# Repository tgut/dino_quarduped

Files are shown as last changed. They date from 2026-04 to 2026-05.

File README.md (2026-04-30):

# Dino Quadruped — 四足机器恐龙

基于 SpotMicro 硬件平台 + CHAMP 软件框架的四足机器恐龙项目，使用强化学习 (PPO) 训练行走策略。

## 项目结构

```
dino_quadruped/
├── urdf/                    # 机器人 URDF 模型
│   └── dino_quadruped.urdf  # 12-DOF SpotMicro 模型
├── rl/                      # 强化学习核心代码
│   ├── dino_env.py          # Gymnasium + PyBullet 仿真环境
│   ├── train_ppo.py         # PPO 训练脚本 (Stable-Baselines3)
│   └── record_eval_video.py # 评估视频录制
├── scripts/                 # 工具脚本
│   ├── benchmark.py         # 性能基准测试
│   ├── sim_standalone.py    # 独立仿真测试
│   └── ...                  # 诊断、可视化等脚本
├── docs/                    # 项目文档
│   ├── rl_v6_training_summary.md  # v6 训练总结报告
│   ├── hardware_architecture.md   # 硬件架构
│   ├── mechanical_design.md       # 机械结构设计
│   └── wiring_diagram.md         # 接线图
├── eval_output/             # 评估产出
│   ├── rl_v6_policy.mp4    # v6 策略行走视频
│   ├── baseline_v6.mp4     # baseline 对比视频
│   ├── training_curves_v6.png # 训练曲线
│   └── eval_v6_summary.json   # 评估指标
├── rl_logs/                 # 训练日志
│   ├── models/              # 模型 checkpoints
│   ├── tensorboard/         # TensorBoard 日志
│   └── training_log.json    # 训练过程记录
├── eval_v6.py               # v6 完整评估流水线
└── README.md
```

## 机器人参数

| 参数 | 值 |
|---|-----|
| 自由度 | 12 DOF (4腿 × 3关节) |
| 体重 | 1.5 kg |
| 体尺寸 | 200×110×60 mm |
| 腿长 | 上腿 100mm + 下腿 100mm |
| 仿真引擎 | PyBullet |

## 快速开始

### 环境安装

```bash
pip install stable-baselines3 gymnasium pybullet numpy
```

### 训练

```bash
# 默认 5M 步，8 并行环境
python rl/train_ppo.py

# 自定义参数
python rl/train_ppo.py --timesteps 2000000 --num-envs 4

# 从 checkpoint 恢复训练
python rl/train_ppo.py --resume
```

### 评估

```bash
# 运行评估 (10 episodes)
python rl/train_ppo.py --eval

# 录制评估视频
python rl/record_eval_video.py

# 完整 v6 评估流水线
python eval_v6.py
```

### TensorBoard 监控

```bash
tensorboard --logdir rl_logs/tensorboard
```

## RL 训练版本演进

| 版本 | 行为 | 核心问题 | 状态 |
|---|---|---|---|
| v1 | 双腿蹦跳 | 步态理解错误 | 已废弃 |
| v2 | 趴在地上 | reward hacking | 已废弃 |
| v3/v4 | 冲刺摔倒 | 速度奖励过大 | 已废弃 |
| v5 | 站着不走 | alive bonus 压制速度奖励 | 已废弃 |
| v6 | 稳定行走 | 腿部抖动 | 基线版本 |
| **v7** | **平滑行走 (开发中)** | 控制频率+平滑惩罚优化 | **当前** |

### v6 成果 (里程碑版本)

- 100% 存活率 (10/10 episodes 跑满 1000 步)
- 前进速度 0.23 m/s (baseline 的 50 倍)
- 行走距离 4.45m (baseline 的 222 倍)

### v7 改进方向 (anti-tremor)

针对 v6 腿部抖动问题的优化：
- 控制频率提升：60Hz → 120Hz (action_repeat 4→2)
- 动作平滑性惩罚加强：-0.015 → -0.04
- 新增关节加速度惩罚：-0.002 × Σ(Δjoint_vel²)
- 足底接触奖励增大：0.15 → 0.25/foot
- 步态相位奖励增大：0.5 → 0.7
- 训练步数延长至 5M

## 技术栈

- **仿真**: PyBullet + Gymnasium
- **算法**: PPO (Stable-Baselines3)
- **并行化**: SubprocVecEnv (8 envs)
- **归一化**: VecNormalize (obs + reward)
- **硬件参考**: SpotMicro + CHAMP

## 项目路线

```
仿真先行 → 硬件点亮 → RL + 特色功能 → 展示
   ✅          ⬜           🔄              ⬜
```

## 可视化工具

### URDF 模型查看

```bash
# 快速 3D 查看（带关节控制）
python3 scripts/quick_view_urdf.py

# 或使用在线 URDF Viewer（无需安装）
# 访问: https://gkjohnson.github.io/urdf-loaders/javascript/example/bundle/
# 拖拽: urdf/dino_quadruped.urdf
```

### DXF 激光切割图查看

```bash
# 在线查看（推荐）
# 访问: https://sharecad.org/
# 上传: cad/body_top.dxf 或 cad/body_bottom.dxf

# 或本地查看
brew install --cask librecad  # macOS
librecad cad/body_bottom.dxf
```

### Three.js 交互式组装图

```bash
# 浏览器打开
open cad/assembly_3d_threejs.html
open cad/assembly_3d_view.html
```

**详细指南**: [可视化工具使用指南](docs/可视化工具使用指南.md)

---

## 📚 文档导航（完整目录）

### 🔧 硬件设计与采购
- [机械结构设计](docs/机械结构设计.md) — 结构尺寸、材料清单、组装步骤
- [硬件架构](docs/硬件架构.md) — 电子元件配置、供电方案
- [硬件对比与升级路线](docs/硬件对比.md) — 版本演进、配置差异
- [四足恐龙采购清单](docs/四足恐龙_淘宝加购清单.html) — 完整购物清单、配件尺寸

### 🦵 腿部结构与3D打印
- [腿部结构详细说明](docs/腿部结构详细说明.md) — 关节配置、舵机位置、轴承支持
- [3D打印件规格](docs/3D打印件规格_淘宝定制.md) — 打印参数、孔位、质量标准
- [STL文件使用说明](cad/STL文件使用说明.md) — 供应商指南、修改说明

### 🚀 软件与部署
- [可视化工具指南](docs/可视化工具使用指南.md) — URDF/DXF/Three.js 查看方法
- [RL v6 训练总结](docs/rl_v6_training_summary.md) — 训练结果、性能基准
- [CHAMP 框架说明](docs/CHAMP框架.md) — 软件架构、环境配置
- [接线图](docs/接线图.md) — 电路连接示意、信号定义
- [硬件验证与集成](docs/硬件验证流程.md) — 点亮、校准、测试流程

### 🎨 可视化
- [Three.js 交互式组装图](cad/assembly_3d_threejs.html) — 实时交互预览，可控制舵机演示动画

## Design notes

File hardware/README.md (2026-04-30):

# 硬件验证脚本

在树莓派上按顺序执行：

```bash
# 0. 安装依赖
pip3 install adafruit-circuitpython-pca9685 adafruit-circuitpython-servokit smbus2 mpu6050-raspberrypi

# 1. I2C 设备扫描（最先跑）
python3 01_i2c_scan.py

# 2. 单个舵机测试（逐个验证12个舵机）
python3 02_servo_test.py --channel 0

# 3. 全部舵机归中（组装前必做）
python3 03_servo_center_all.py

# 4. IMU 数据读取验证
python3 04_imu_test.py

# 5. 站立姿态（组装完成后）
python3 05_stand_test.py

# 6. 行走测试
python3 06_trot_test.py
```

# 测试结果

```bash
# 04 imu测试结果：

pi@raspberrypi:~/hardware $ python3 04_imu_test.py 
==================================================
  Dino Quadruped - IMU 测试
==================================================
[警告] WHO_AM_I = 0x70, 预期 0x68

--- 快速检查 ---
请将机器人水平放置...

  平均加速度: X= +3.02  Y= -1.17  Z= +9.77 m/s²
  总加速度:   10.29 m/s² (理想值: 9.81)
  Roll:  -6.8°  Pitch: -16.7° (水平时应接近 0°)

结果:
  [OK  ] Z 轴读数: 9.77 m/s²
  [FAIL] X/Y 轴漂移: X=3.02, Y=-1.17
  [OK  ] 总 G 值: 10.29 m/s²
  [FAIL] 水平度: roll=-6.8°, pitch=-16.7°

[警告] 有项目未通过，请检查:
  - IMU 是否水平安装
  - 接线是否正确 (3.3V 供电, I2C)
  - 安装方向: 芯片面朝上, X 轴朝前

--- 持续读取 (Ctrl+C 停止) ---

 Accel X  Accel Y  Accel Z  |   Gyro X  Gyro Y  Gyro Z  |    Roll  Pitch
--------------------------------------------------------------------------------
^C -1.02    +1.86    +9.93  |     -1.9    -0.8    -0.4  |    +9.7   +5.8
```

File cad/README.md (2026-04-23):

# CAD 图纸说明

## 文件列表

| 文件 | 用途 | 板材 |
|---|---|---|
| `generate_dxf.py` | DXF 生成脚本（修改此文件后重新运行） |
| `body_top.dxf` | 顶板激光切割图 | 200×110mm, 3mm 亚克力 |
| `body_bottom.dxf` | 底板激光切割图 | 200×110mm, 3mm 亚克力 |

重新生成: `python3 cad/generate_dxf.py`

---

## 图层说明

| 图层 | 颜色 | 用途 | 激光切割操作 |
|---|---|---|---|
| OUTLINE | 白色 | 外轮廓 | 切割（切透） |
| HOLES | 红色 | 圆孔（螺丝/扎带） | 切割（切透） |
| SLOTS | 绿色 | 矩形槽/大开口 | 切割（切透） |
| ENGRAVE | 蓝色 | 标注框/文字 | 雕刻（不切透）或不加工 |

---

## body_top.dxf 顶板孔位清单

坐标系: 左下角 (0,0), 右上角 (200,110), 单位 mm。

```
  Y=110 ┌───────────────────────────────────────────────┐
        │ S3            S5                       S8     │
  Y=100 │(10,100)      (100,100)               (190,100)│
        │                                               │
        │  [LM2596#1 5V]  cx=150 cy=90                  │
        │  4×M3孔 37×15mm                               │
        │                                               │
        │  [RPi 3B]  cx=60 cy=65                        │
        │  4×M2.5孔 58×49mm                             │
        │                                               │
   Y=55 │ S2(10,55)    [LM2596#2 6V] cx=150 cy=63 S7(190,55)│
        │              4×M3孔 37×15mm                   │
        │                                               │
        │  [MPU6050]                                    │
        │  cx=105 cy=45                                 │
        │  2×Φ2扎带孔                                   │
        │   [BATTERY] x[125,180] y[38,68]               │
        │   4×Φ3.5扎带孔 + 2个魔术贴槽                   │
        │                                               │
        │  [PCA9685] cx=60 cy=31  (SW) Φ16.5           │
        │  4×Φ2孔 19×55mm       cx=130 cy=10           │
        │                                               │
   Y=0  │ S1(10,10)    S4(100,10)               S6(190,10)│
        └───────────────────────────────────────────────┘
  X=0                   X=100                         X=200

  USB开口: 左边缘 x[0,3.5] y[58,76]
```

### 1. 铜柱孔 — 8×M3 (Φ3.2mm)

连接顶板和底板的 M3×30mm 六角铜柱。

| 编号 | 坐标 | 位置 |
|---|---|---|
| S1 | (10, 10) | 左下 |
| S2 | (10, 55) | 左中 |
| S3 | (10, 100) | 左上 |
| S4 | (100, 10) | 中下 |
| S5 | (100, 100) | 中上 |
| S6 | (190, 10) | 右下 |
| S7 | (190, 55) | 右中 |
| S8 | (190, 100) | 右上 |

### 2. 树莓派 3B — 4×M2.5 (Φ2.7mm)

固定树莓派主板，标准 58×49mm 孔距。中心 (60, 65)。

| 坐标 | 位置 |
|---|---|
| (31, 40.5) | 左下 |
| (89, 40.5) | 右下 |
| (31, 89.5) | 左上 |
| (89, 89.5) | 右上 |

安装方式: M2.5×6 铜柱 + M2.5 螺丝。

### 3. PCA9685 — 4×Φ2mm (Φ2.2mm)

PWM 舵机驱动板，实测 25×61mm，四角安装孔 Φ2mm（距边缘 3mm）。中心 (60, 31)。

| 坐标 | 位置 |
|---|---|
| (50.5, 3.5) | 左下 |
| (69.5, 3.5) | 右下 |
| (50.5, 58.5) | 左上 |
| (69.5, 58.5) | 右上 |

安装方式: M2×6 螺丝 + M2 螺母，或 M2 铜柱架高散热。

### 4. MPU6050 (GY-521) — 2×扎带孔 (Φ2mm)

GY-521 模块 15×20mm，无安装孔，仅排针。

| 坐标 | 位置 |
|---|---|
| (94.5, 45) | 模块左侧 |
| (115.5, 45) | 模块右侧 |

固定方式:
1. 模块焊排针，插入排针座（焊在小块万能板上）
2. 万能板用双面胶粘贴在标注位置
3. 穿细扎带（Φ2mm 孔）压住模块防脱落

### 5. 电池 (2S 5000mAh) — 4×扎带孔 (Φ3.5mm) + 2×魔术贴槽

电池区域 x[125, 180] y[38, 68]。

| 特征 | 坐标/范围 | 用途 |
|---|---|---|
| 扎带孔 | (130, 43) | 左下角 |
| 扎带孔 | (175, 43) | 右下角 |
| 扎带孔 | (130, 63) | 左上角 |
| 扎带孔 | (175, 63) | 右上角 |
| 魔术贴槽 | x[145,160] y[46.5,49.5] | 上侧穿魔术贴带 |
| 魔术贴槽 | x[145,160] y[61.5,64.5] | 下侧穿魔术贴带 |

固定方式: 魔术贴带穿过槽绕电池一圈，四角扎带辅助防滑。

### 6. LM2596 #1 (5V) — 4×M3 (Φ3.2mm)

给树莓派供 5V 的降压模块。孔距 37×15mm，中心 (150, 90)。

| 坐标 | 位置 |
|---|---|
| (131.5, 82.5) | 左下 |
| (168.5, 82.5) | 右下 |
| (131.5, 97.5) | 左上 |
| (168.5, 97.5) | 右上 |

安装方式: M3×8 螺丝 + M3 螺母（或 M3×6 铜柱）。

### 7. LM2596 #2 (6V) — 4×M3 (Φ3.2mm)

给舵机供 6V 的降压模块。孔距 37×15mm，中心 (150, 63)。

| 坐标 | 位置 |
|---|---|
| (131.5, 55.5) | 左下 |
| (168.5, 55.5) | 右下 |
| (131.5, 70.5) | 左上 |
| (168.5, 70.5) | 右上 |

### 8. 电源开关 — Φ16.5mm

16mm 金属钮子开关（带灯，12-24V，10A）。中心 (130, 10)。

安装方式: 开关自带螺纹，穿过 Φ16.5mm 孔后用配套螺母锁紧。

### 9. USB 接口开口 — 矩形槽

左侧边缘 U 型开口，范围 x[0, 3.5] y[58, 76]。
方便树莓派 USB 口从侧面插拔线缆。

---

## body_bottom.dxf 底板孔位清单

```
  Y=110 ┌───────────────────────────────────────────────┐
        │ S3                                     S8     │
  Y=100 │                                               │
        │  ◎ (30,85)               ◎ (170,85)          │
        │  舵机左后                  舵机右后             │
        │                                               │
        │  ○走线孔(100,80)                               │
   Y=55 │ S2   ┌──────── 走线槽 ────────┐         S7   │
        │      │  x[55,145] y[50,60]    │               │
        │      └────────────────────────┘               │
        │  ○走线孔(100,30)                               │
        │                                               │
        │  ◎ (30,25)               ◎ (170,25)          │
        │  舵机左前                  舵机右前             │
   Y=10 │ S1           S4                       S6     │
        └───────────────────────────────────────────────┘
```

### 1. 铜柱孔 — 8×M3 (Φ3.2mm)

与顶板完全对应（同 8 个位置）。

### 2. 舵机安装孔 — 每角 4×M3 (Φ3.2mm) + 轴槽

四角各安装 1 个 DS3218 髋关节舵机。

| 舵机 | 中心 | 安装孔间距 | 轴槽 |
|---|---|---|---|
| 左前 | (30, 25) | 50×20mm | 20×12mm |
| 右前 | (170, 25) | 50×20mm | 20×12mm |
| 左后 | (30, 85) | 50×20mm | 20×12mm |
| 右后 | (170, 85) | 50×20mm | 20×12mm |

每个舵机: 4×M3 螺丝固定舵机底座，中央矩形槽供舵机输出轴穿过。

### 3. 走线槽 — 中央矩形开口

x[55, 145] y[50, 60]，90×10mm 长条形开口。
舵机线缆从底板穿到上方连接 PCA9685。

### 4. 走线孔 — 2×Φ8mm

| 坐标 | 位置 |
|---|---|
| (100, 30) | 前侧舵机区 |
| (100, 80) | 后侧舵机区 |

辅助线缆通道。

---

## 组装顺序

```
Step 1: 底板安装铜柱
  底板 8×M3 孔 → 拧入 M3×30 铜柱（公头朝上）

Step 2: 底板安装髋关节舵机
  四角各 4×M3 螺丝固定 DS3218
  舵机轴穿过中央矩形槽

Step 3: 顶板安装电子元件
  - RPi 3B: 4×M2.5 铜柱+螺丝
  - PCA9685: 待实测孔距（暂用双面胶固定）
  - MPU6050: 排针座+双面胶+扎带
  - LM2596 ×2: 各 4×M3 螺丝
  - 电源开关: 穿入 Φ16.5 孔，螺母锁紧

Step 4: 合体
  顶板对准铜柱 → 8×M3 螺母锁紧
  穿线: 舵机线经走线槽/孔到达顶板 PCA9685

Step 5: 电池 + 接线
  电池放入标注区 → 魔术贴带穿槽绑紧 → 扎带加固
  按 docs/接线图.md 连接电源线路
```

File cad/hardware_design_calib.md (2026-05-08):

# 硬件设计校准文档

## 📐 舵机实际尺寸（DS3218）

### 从附件截图测得的尺寸

#### 舵机本体
- **长度**: 40.5mm (1.58in)
- **宽度**: 20mm (0.78in)
- **高度**: 
  - 主体高度: 41mm (1.61in)
  - 总高度（含舵盘）: 45mm
  - 舵机底座到中心轴: 45mm

#### 舵机安装孔位
- **安装耳宽度**: 48mm (标准DS3218)
- **安装孔间距**: 10mm (底部两个孔)
- **安装孔直径**: Φ3mm (推荐 Φ3.2mm 用于 M3 螺丝)

#### 舵机摇臂（舵盘）
- **舵盘外径**: ~23.5mm
- **舵盘基座宽度**: 19.5mm
- **舵盘厚度**: ~4mm
- **中心轴直径**: Φ5-6mm
- **舵盘固定孔**: M2 螺丝，对称分布

---

## ⚠️ 当前 STL 设计问题分析

### 1. hip_bracket_detailed.stl（髋关节支架）

#### 当前设计尺寸
```
主体盒子: 20×40×50mm
舵机安装孔: 4 个 Φ3.2mm
轴承孔: 2 个 Φ5mm
```

#### 问题诊断

**❌ 问题 1: 主体尺寸不足**
- **当前**: 20mm (宽) × 40mm (深) × 50mm (高)
- **实际需要**: 至少 25mm (宽) × 45mm (深) × 55mm (高)
- **原因**: 舵机本体 40.5mm 长，加上安装耳 48mm，当前盒子无法容纳

**❌ 问题 2: 舵机孔位不准确**
- **当前**: 4 个孔，位置 ±8mm, ±15mm (估算)
- **实际需要**: 基于 DS3218 标准孔距 48mm × 10mm
- **修正**: 孔位应为 ±24mm (横向) × ±5mm (纵向)

**❌ 问题 3: 缺少舵机容纳空间**
- **当前**: 实心盒子 + 孔
- **实际需要**: U 型支架，中间需要挖空 42mm × 22mm × 45mm 用于容纳舵机本体

#### 修正方案
```
新尺寸:
- 主体: 26×50×60mm (增大以容纳舵机)
- 舵机容纳槽: 42×22×45mm (U型槽)
- 安装孔位置: 
  - 前左: [-24, -5, 25]
  - 前右: [24, -5, 25]
  - 后左: [-24, 5, 25]
  - 后右: [24, 5, 25]
- 轴承孔: Φ5mm (MR105ZZ 轴承外径)，位于两侧壁中心
```

---

### 2. knee_bracket_detailed.stl（膝关节支架）

#### 当前设计尺寸
```
主体盒子: 15×30×40mm
舵机安装孔: 4 个 Φ3.2mm
轴承孔: 2 个 Φ5mm
```

#### 问题诊断

**❌ 问题: 尺寸过小**
- **当前**: 15×30×40mm
- **实际需要**: 至少 25×45×55mm（与髋关节支架类似）
- **原因**: 膝关节也需要容纳相同的 DS3218 舵机

#### 修正方案
```
新尺寸:
- 主体: 25×45×55mm
- 舵机容纳槽: 42×22×45mm
- 安装孔位置: 同髋关节支架
```

---

### 3. upper_leg_detailed.stl（上腿连杆）

#### 当前设计尺寸
```
空心圆管: Φ10×100mm (外径Φ10, 内径Φ6)
连接耳: 15mm × 5mm
M3 孔: Φ3.2mm
```

#### 问题诊断

**✅ 尺寸合理**
- 上腿长度 100mm 符合设计
- 空心管 Φ10 强度足够
- 连接耳尺寸适中

**⚠️ 小问题: 连接耳厚度**
- **当前**: 5mm 厚
- **建议**: 6-8mm 厚（增加强度）

#### 修正方案
```
优化尺寸:
- 连接耳厚度: 5mm → 7mm
- M3 孔深度: 确保穿透 7mm
```

---

### 4. lower_leg_detailed.stl（下腿连杆）

#### 当前设计尺寸
```
空心圆管: Φ8×100mm (外径Φ8, 内径Φ5)
连接耳: 12mm × 4mm
脚垫孔: Φ15mm × 5mm深
```

#### 问题诊断

**✅ 尺寸合理**
- 下腿长度 100mm 符合设计
- 脚垫孔 Φ15mm 可以插入硅胶脚垫

**⚠️ 小问题: 连接耳厚度**
- **当前**: 4mm 厚
- **建议**: 6mm 厚

#### 修正方案
```
优化尺寸:
- 连接耳厚度: 4mm → 6mm
```

---

### 5. horn_adapter_detailed.stl（摇臂转接件）

#### 当前设计尺寸
```
圆盘: Φ25×4mm
中心轴孔: Φ6mm
M2 固定孔: 4 个 Φ2.2mm
```

#### 问题诊断

**✅ 尺寸基本合理**
- 圆盘直径 Φ25mm 与舵盘 Φ23.5mm 接近
- 中心轴孔 Φ6mm 符合舵机轴直径

**⚠️ 小问题: M2 孔位置**
- **当前**: 固定孔位于 9mm 半径处
- **实际**: 需要根据舵盘实际孔位调整（通常 6-8mm 半径）

#### 修正方案
```
优化尺寸:
- M2 固定孔半径: 9mm → 7mm（更贴近舵盘中心）
- 确认舵盘实际孔位后再调整
```

---

## 📋 body_bottom.dxf 设计问题

### DXF 文件实际检测结果

**✅ 整体尺寸**: 200mm × 110mm（足够容纳所有元件）  
**✅ 孔数量**: 26 个圆形孔，半径 1.6mm (Φ3.2mm，适配 M3 螺丝)  
**⚠️ 舵机孔位问题**: 部分孔距不符合 DS3218 标准

### 孔位坐标分析

| 孔编号 | 坐标 (x, y) | 用途推测 | 状态 |
|---|---|---|---|
| 1-3 | (10, 10), (10, 55), (10, 100) | 左侧边缘固定孔 | ✅ |
| 4-5 | (100, 10), (100, 100) | 中心线固定孔 | ✅ |
| 6-8 | (190, 10), (190, 55), (190, 100) | 右侧边缘固定孔 | ✅ |
| 9-10 | (5, 15), (5, 35) | 左前舵机孔（间距20mm） | ❌ 应为10mm |
| 11-12 | (55, 15), (55, 35) | 左前舵机孔（间距20mm） | ❌ 应为10mm |
| 13-14 | (145, 15), (145, 35) | 右前舵机孔（间距20mm） | ❌ 应为10mm |
| 15-16 | (195, 15), (195, 35) | 右前舵机孔（间距20mm） | ❌ 应为10mm |
| 17-20 | (5, 75), (5, 95), (55, 75), (55, 95) | 后腿舵机孔（间距20mm） | ❌ 应为10mm |

### ❌ 主要问题

**问题 1: 舵机安装孔间距错误**
- **当前**: 垂直间距 20mm (35-15=20)
- **标准**: DS3218 孔距应为 **10mm**
- **影响**: 舵机无法安装，孔位不对齐

**问题 2: 舵机横向间距也需验证**
- **当前**: 孔 9 到孔 11 间距 50mm (55-5=50)
- **标准**: DS3218 安装耳宽度 **48mm**
- **差距**: 2mm 偏差，需要调整

**问题 3: 树莓派/PCA9685 孔位未检测到**
- **预期**: 应有树莓派 4 个 M2.5 孔（58×49mm）
- **预期**: 应有 PCA9685 孔位
- **实际**: DXF 中未找到明显的电路板安装孔

### 修正方案

```
舵机孔位修正:
- 垂直间距: 20mm → 10mm
- 左前腿孔位: (5, 20) 和 (5, 30) [间距10mm]
- 右前腿孔位: (145, 20) 和 (145, 30)
- 同时调整横向距离为精确 48mm

新增电路板安装孔:
- 树莓派 3B: 4 个 Φ2.5mm 孔，58mm × 49mm 矩形
- PCA9685: 4 个 Φ2.5mm 孔，25.4mm × 22.9mm 矩形
- MPU6050: 4 个 Φ2mm 孔，20mm × 16mm 矩形
```

---

---

## 🔋 body_top.dxf 电池尺寸问题

### DXF 文件实际检测结果

**✅ 整体尺寸**: 200mm × 110mm  
**⚠️ 电池槽尺寸严重不足**

### 检测到的矩形区域

| 序号 | 尺寸 (长×宽) | 位置 (x, y) | 用途推测 | 状态 |
|---|---|---|---|---|
| 1 | 85×56mm | (18, 37) | 主元件区域 | ✅ |
| 2 | 25×61mm | (47.5, 0.5) | 未知 | ❓ |
| 3 | 15×20mm | (97.5, 35) | 小元件固定 | ✅ |
| **4** | **55×30mm** | **(125, 38)** | **电池槽** | **❌ 太小** |
| 5 | 15×3mm | (145, 46.5) | 走线槽 | ✅ |

### ❌ 严重问题：电池槽尺寸不足

**实际电池尺寸（从采购清单）**:
- **型号**: 格氏 ACE RedRock 5000mAh 2S 7.4V 70C
- **尺寸**: **132mm × 40mm × 17mm** (长×宽×厚)
- **重量**: ~250g
- **接口**: XT60

**当前 DXF 设计**:
- **电池槽**: 55mm × 30mm (矩形4 @ 125, 38)
- **问题**: 
  - 长度不足: 55mm << 132mm (差距 **77mm**)
  - 宽度不足: 30mm < 40mm (差距 **10mm**)
  - **结论**: 电池完全无法放入！

### 📐 修正方案

#### 方案 1: 调整电池槽尺寸（推荐）

```
新电池槽尺寸:
- 长度: 55mm → 135mm (留3mm余量)
- 宽度: 30mm → 42mm (留2mm余量)
- 位置: 需要重新规划，确保不与其他元件冲突

检查清单:
□ 电池槽位置是否与树莓派/PCA9685/舵机冲突？
□ 132mm 长度在 200mm 板上是否能横向放置？
□ 是否需要增加电池固定孔（魔术贴或尼龙扎带）？
□ XT60 接口是否有足够空间伸出？
```

#### 方案 2: 更换为更小电池（不推荐）

```
备选电池规格:
- 格氏 2200mAh 2S 7.4V
- 尺寸: ~105mm × 34mm × 16mm
- 问题: 容量减半，续航时间大幅下降
```

#### 方案 3: 电池外挂（临时方案）

```
将电池通过魔术贴固定在机身板下方:
- 优点: 不需要修改 DXF
- 缺点: 
  - 重心偏低（可能影响稳定性）
  - 增加整机高度
  - 电池易脱落
```

### 🔧 推荐实施步骤

1. **验证实际电池尺寸**
   - 收到电池后用游标卡尺实测
   - 确认 132×40×17mm 是否准确

2. **重新设计 body_top.dxf**
   - 将电池槽改为 135×42mm
   - 横向放置在机身板中央
   - 避开树莓派和 PCA9685 位置
   - 添加 4 个 Φ3mm 固定孔用于魔术贴或扎带

3. **导出新 DXF 文件**
   ```bash
   # 使用 ezdxf 修改
   python3 update_body_top_battery.py
   ```

4. **激光切割前验证**
   - 打印 1:1 纸质模板
   - 放置实际电池验证尺寸
   - 确认所有元件位置无冲突

---

## ✅ 修正优先级

### 🚨 紧急优先级（必须立即修改，否则无法组装）
1. **body_top.dxf** - 电池槽尺寸严重不足 (55×30mm vs 132×40mm)
2. **body_bottom.dxf** - 舵机孔位间距错误 (20mm vs 标准10mm)

### 高优先级（必须修改）
3. **hip_bracket.stl** - 主体尺寸不足，无法容纳舵机
4. **knee_bracket.stl** - 主体尺寸不足

### 中优先级（建议修改）
4. **upper_leg.stl** - 连接耳厚度增加
5. **lower_leg.stl** - 连接耳厚度增加

### 低优先级（可选优化）
6. **horn_adapter.stl** - 固定孔位置微调

---

## 🔧 下一步行动

### 1. 读取并验证 body_bottom.dxf
```bash
# 使用 ezdxf 或 dxfgrabber 读取 DXF 文件
python3 -c "import ezdxf; doc = ezdxf.readfile('body_bottom.dxf'); print(doc.entities)"
```

### 2. 重新生成支架 STL
修改 `generate_stl_detailed.py` 中的尺寸参数:
- hip_bracket: 20×40×50mm → 26×50×60mm
- knee_bracket: 15×30×40mm → 25×45×55mm

### 3. 验证与实物对比
- 用数字游标卡尺测量实际舵机尺寸
- 3D 打印一个测试件验证孔位
- 调整偏差后再批量打印

---

## 📊 舵机规格总结

### 从附件截图测得

| 参数 | 数值 | 备注 |
|---|---|---|
| 型号 | DS3218 或类似 20Kg 舵机 | 数字舵机 |
| 扭矩 | 20Kg·cm | 6.4V-6.8V |
| 长度 | 40.5mm | ±0.5mm |
| 宽度 | 20mm | ±0.5mm |
| 高度 | 41-45mm | 不含/含舵盘 |
| 安装耳宽度 | 48mm | 标准 DS3218 |
| 安装孔间距 | 10mm | 底部两孔 |
| 舵盘直径 | 23.5mm | 摇臂外径 |
| 舵盘基座 | 19.5mm | 中心凸起部分 |
| 中心轴 | Φ5-6mm | 十字/圆形 |
| 重量 | ~60g | 估算 |

### 从采购清单验证（订单数据.xlsx）

| 项目 | 数值 | 来源 |
|---|---|---|
| 型号 | DS3218MG | 淘宝订单 |
| 描述 | 防水数字舵机合金齿轮 | 模型基地 |
| 角度 | 270° | 规格说明 |
| 扭矩 | 20KG | 商品标题 |
| 单价 | ￥75.00 | 订单金额 |
| 数量 | 1 个（测试） | 已验证通过 |
| 备注 | 后续需购买 11 个 | 总需 12 个舵机 |

---

**文档版本**: v1.1  
**创建日期**: 2026-05-08  
**更新日期**: 2026-05-08（已验证 DXF 文件，发现孔位问题）  
**下次更新**: 修正 DXF 孔位后更新

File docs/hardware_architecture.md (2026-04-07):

# Dino Quadruped - Hardware Architecture

## System Block Diagram

```
                    ┌─────────────────────────────────────────────┐
                    │              2S 7.4V LiPo                   │
                    │           5000mAh 30C XT60                  │
                    └──────────┬──────────────┬───────────────────┘
                               │              │
                          ┌────┴────┐    ┌────┴────┐
                          │ LM2596  │    │ LM2596  │
                          │ Buck #1 │    │ Buck #2 │
                          │ → 5V 3A │    │ → 6V 5A │
                          └────┬────┘    └────┬────┘
                               │              │
                    ┌──────────┴──┐     ┌─────┴──────────────┐
                    │             │     │                     │
               ┌────┴────┐       │  ┌──┴──────────────┐     │
               │  RPi 3B │       │  │   PCA9685        │     │
               │         │◄─I2C─┤  │  16-ch PWM       │     │
               │  GPIO    │      │  │  Servo Driver    │     │
               │  I2C     │      │  └──┬──┬──┬──┬──┬──┘     │
               │  UART    │      │     │  │  │  │  │         │
               └────┬────┘      │     │  │  │  │  │    6V───┘
                    │           │     │  │  │  │  │
               ┌────┴────┐     │  ┌──┴──┴──┴──┴──┴──────────┐
               │ MPU6050 │     │  │   12× DS3218 Servos      │
               │  IMU    │◄I2C─┘  │   20kg·cm 270°           │
               │ GY-521  │        │                           │
               └─────────┘        │  FL: hip/shoulder/knee    │
                                  │  FR: hip/shoulder/knee    │
                                  │  RL: hip/shoulder/knee    │
                                  │  RR: hip/shoulder/knee    │
                                  └───────────────────────────┘
```

## Power Architecture

```
 Battery 7.4V
     │
     ├──► 10A Power Switch
     │
     ├──► LM2596 #1 ──► 5V 3A ──► Raspberry Pi 3B (via GPIO 5V/GND)
     │                         ├──► PCA9685 VCC (logic, 3.3~5V)
     │                         └──► MPU6050 VCC (3.3~5V)
     │
     └──► LM2596 #2 ──► 6V 5A ──► PCA9685 V+ (servo power rail)
                                └──► 12× DS3218 Servos
```

### Power Budget

| Consumer | Voltage | Current (typ) | Current (peak) | Notes |
|---|---|---|---|---|
| RPi 3B | 5V | 0.7A | 1.2A | WiFi + GPIO active |
| PCA9685 logic | 5V | 0.01A | 0.02A | I2C logic only |
| MPU6050 | 3.3V | 0.004A | 0.004A | From Pi 3.3V rail  |
| DS3218 ×12 idle | 6V | 0.6A total | - | 50mA each idle |
| DS3218 ×12 load | 6V | 3.6A total | 12A | 300mA typ, 1A peak |
| **Total** | - | **~5A** | **~13A** | |

- Battery: 5000mAh @ 7.4V → ~37Wh
- Runtime estimate: 37Wh / (6V × 5A) ≈ **60~90 min** (mixed walking)
- Peak current: 12A (all servos stall) — 30C battery = 150A capacity, safe

### Safety Notes

- XT60 connectors rated 60A continuous
- LM2596 #2 (servo rail): 5A continuous, ok for typical load; add heatsink
- Consider upgrade to XL4016 (8A) if servos stall frequently
- Battery low-voltage alarm recommended (2S buzzer, ¥5)

## Communication Bus

### I2C Bus (400kHz)

```
RPi 3B (SDA=GPIO2, SCL=GPIO3)
    │
    ├──► PCA9685   Address: 0x40 (default)
    │    - 16-channel, 12-bit PWM
    │    - 50Hz for servo control
    │    - Channels 0-11 used (12 servos)
    │
    └──► MPU6050   Address: 0x68 (default)
         - 6-axis IMU (accel + gyro)
         - 1kHz internal sample rate
         - Read at 100~200Hz in control loop
```

### Servo Channel Mapping (PCA9685)

| Channel | Joint | URDF Joint Name | Servo ID |
|---|---|---|---|
| 0 | Front-Left Hip | fl_hip_joint | S0 |
| 1 | Front-Left Shoulder| fl_shoulder_joint | S1 |
| 2 | Front-Left Knee | fl_knee_joint | S2 |
| 3 | Front-Right Hip | fr_hip_joint | S3 |
| 4 | Front-Right Shoulder| fr_shoulder_joint | S4 |
| 5 | Front-Right Knee | fr_knee_joint | S5 |
| 6 | Rear-Left Hip | rl_hip_joint | S6 |
| 7 | Rear-Left Shoulder | rl_shoulder_joint | S7 |
| 8 | Rear-Left Knee | rl_knee_joint | S8 |
| 9 | Rear-Right Hip | rr_hip_joint | S9 |
| 10 | Rear-Right Shoulder| rr_shoulder_joint | S10 |
| 11 | Rear-Right Knee | rr_knee_joint | S11 |
| 12-15 | Reserved | (tail/head future) | - |

## Control Loop Architecture

```
┌──────────────────────────────────────────────────────┐
│                  Raspberry Pi 3B                      │
│                                                       │
│  ┌─────────────┐   ┌──────────────┐   ┌───────────┐ │
│  │   Gait      │──►│     IK       │──►│ PCA9685   │─┤──► Servos
│  │  Generator  │   │   Solver     │   │  Driver   │ │
│  │  (Python)   │   │  (Analytical)│   │  (I2C)    │ │
│  └──────┬──────┘   └──────────────┘   └───────────┘ │
│         │                                             │
│  ┌──────┴──────┐                                      │
│  │  IMU Reader │◄─────────────────────────────────────┤──► MPU6050
│  │  + PID      │                                      │
│  │ (Yaw/Pitch) │                                      │
│  └─────────────┘                                      │
│                                                       │
│  Target: 50Hz control loop (20ms per cycle)           │
└──────────────────────────────────────────────────────┘
```

### Software Stack on Pi

```
Layer 3: Gait Planner     (stand/trot/crawl, RL policy future)
Layer 2: IK + PID         (analytical IK, yaw/pitch/roll PID)
Layer 1: HAL Drivers      (PCA9685 PWM, MPU6050 IMU, GPIO)
Layer 0: Linux (Raspbian)  + Python 3.9+
```

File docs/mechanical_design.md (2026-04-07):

# Dino Quadruped - Mechanical Structure Design

## Overall Dimensions

```
                 ┌─── 200mm ───┐
                 │              │
            ┌────┼──────────────┼────┐
            │    │              │    │  ── 110mm ──
            │    │   Body Plate │    │
            └────┼──────────────┼────┘
                 │              │
                 └──────────────┘

  Side View:
                  ┌──────────────────┐  ← Body plate (60mm tall)
                  │    Electronics   │
                  └──┬──────────┬───┘
                     │          │
              ┌──────┤          ├──────┐  ← Shoulder joints
              │Upper │          │Upper │
              │ Leg  │          │ Leg  │  100mm
              │100mm │          │100mm │
              ├──────┤          ├──────┤  ← Knee joints
              │Lower │          │Lower │
              │ Leg  │          │ Leg  │  100mm
              │100mm │          │100mm │
              ◙──────┘          └──────◙  ← Feet (15mm rubber)
         ─────────────────────────────────── Ground
              │◄── 190mm stance ──►│
              │                    │
              Standing height: ~150mm (from URDF simulation)
```

## Frame Structure

### Body Frame (Acrylic Laser Cut)

Two acrylic plates (3mm thick) sandwiched with standoffs:

```
  Top Plate (3mm acrylic):
  ┌────────────────────────────────────────┐
  │  ○          ○           ○          ○   │  ← M3 standoff holes
  │     ┌──────────┐   ┌──────────┐        │
  │     │ Pi 3B    │   │ Battery  │        │
  │     │ mount    │   │ velcro   │        │
  │     └──────────┘   └──────────┘        │
  │  ○    ┌────────┐                   ○   │
  │       │PCA9685 │   ┌──────┐            │
  │       │ mount  │   │MPU6050│           │
  │       └────────┘   └──────┘            │
  │  ○          ○           ○          ○   │
  └────────────────────────────────────────┘
      200mm × 110mm

  Bottom Plate (3mm acrylic):
  ┌────────────────────────────────────────┐
  │  ◎          ◎           ◎          ◎   │  ← Servo mount holes
  │                                        │  (4 corners for hip servos)
  │  ○          ○           ○          ○   │  ← Standoff holes
  │                                        │
  │        ████████████████████            │  ← Wire channel slots
  │                                        │
  │  ○          ○           ○          ○   │
  │                                        │
  │  ◎          ◎           ◎          ◎   │
  └────────────────────────────────────────┘
      200mm × 110mm

  Standoff spacing: 30mm height (M3 × 30mm brass standoffs)
  Total body height: 3 + 30 + 3 = 36mm
```

### Leg Assembly (Per Leg)

```
  Exploded View (single leg):

  ┌─────────────────────┐
  │  Hip Servo (DS3218)  │  ← Mounted to body bottom plate
  │  Rotation: X-axis    │     with aluminum U-bracket
  └─────────┬───────────┘
            │ servo horn
  ┌─────────┴───────────┐
  │  Hip Bracket         │  ← 3D printed PLA or aluminum U-bracket
  │  (40mm offset)       │     provides lateral offset
  └─────────┬───────────┘
            │
  ┌─────────┴───────────┐
  │  Shoulder Servo      │  ← Mounted sideways in U-bracket
  │  Rotation: Y-axis    │
  └─────────┬───────────┘
            │ servo horn
  ┌─────────┴───────────┐
  │  Upper Leg Link      │  ← Aluminum bracket or 3D printed
  │  Length: 100mm       │     DS3218 mounting holes included
  │  (2× M3 holes each) │
  └─────────┬───────────┘
            │
  ┌─────────┴───────────┐
  │  Knee Servo          │  ← Mounted at upper/lower leg joint
  │  Rotation: Y-axis    │
  └─────────┬───────────┘
            │ servo horn
  ┌─────────┴───────────┐
  │  Lower Leg Link      │  ← Aluminum or 3D printed
  │  Length: 100mm       │
  └─────────┬───────────┘
            │
         ┌──┴──┐
         │Foot │  ← Silicone hemisphere 15mm
         │ Pad │     press-fit or glued
         └─────┘
```

### Joint Detail (Shoulder/Knee)

```
  Cross-section of shoulder joint:

        Upper bracket
       ┌────────────┐
       │  ┌──────┐  │
       │  │Servo │  │
       │  │DS3218│  │  ← Servo body in U-bracket
       │  │      │  │     secured with 4× M3 screws
       │  └──┬───┘  │
       └─────┼──────┘
             │
        ┌────┴────┐
        │ Bearing │  ← MR105ZZ (5×10×4mm)
        │ 5×10×4  │     on opposite side of servo
        └────┬────┘     for dual-support
             │
        ┌────┴────────────────────┐
        │    Upper Leg Link       │
        │    (100mm aluminum)     │
        └─────────────────────────┘
```

## Bill of Structural Materials

### Laser Cut Parts (Acrylic 3mm)

| Part | Qty | Material | DXF File |
|---|-----|---|---|
| Top body plate | 1 | Acrylic 3mm | body_top.dxf |
| Bottom body plate | 1 | Acrylic 3mm | body_bottom.dxf|

### 3D Printed Parts (PLA)

| Part | Qty | Material | STL File |
|---|-----|---|---|
| Hip bracket | 4 | PLA | hip_bracket.stl |
| Upper leg link | 4 | PLA/Alu | upper_leg.stl |
| Lower leg link | 4 | PLA/Alu | lower_leg.stl |
| Servo horn adapter| 12  | PLA | horn_adapter.stl |

Note: STL files to be generated from SpotMicro community designs,
modified to match our URDF dimensions. See `cad/` directory (TODO).

### Standard Hardware

| Part | Spec | Qty  |
|---|---|---|
| M3×8 socket cap | Stainless steel | 60 |
| M3×12 socket cap | Stainless steel | 24 |
| M3×30 standoff | Brass, M/F | 8 |
| M3 nut | Stainless steel | 40 |
| M3 washer | Stainless steel | 40 |
| M2×8 self-tapping | For servo horn | 24 |
| MR105ZZ bearing | 5×10×4mm | 16 |
| Servo U-bracket | Aluminum, for DS3218 | 12 |
| Silicone foot pad | Hemisphere 15mm | 4 |
| Zip ties 100mm | Nylon | 50 |
| Velcro strap 20mm | For battery mount | 2 |

## Assembly Order

```
Phase 1: Body Frame
  1. Laser cut top + bottom acrylic plates
  2. Install 8× M3 standoffs on bottom plate
  3. Mount 4× hip servos to bottom plate corners
  4. Attach top plate

Phase 2: Leg Assembly (×4)
  1. Install shoulder servo in hip bracket
  2. Attach hip bracket to hip servo horn
  3. Attach upper leg link to shoulder servo horn
  4. Install knee servo at upper/lower leg junction
  5. Attach lower leg link to knee servo horn
  6. Press-fit foot pad at bottom

Phase 3: Electronics
  1. Mount PCA9685 on top plate (M2.5 standoffs)
  2. Mount MPU6050 at body center (double-sided tape)
  3. Mount Pi 3B (M2.5 standoffs)
  4. Wire I2C bus (PCA9685 + MPU6050)
  5. Connect all 12 servo cables to PCA9685
  6. Mount LM2596 modules
  7. Wire power (battery → switch → buck converters)
  8. Velcro-strap battery to top plate

Phase 4: Calibration
  1. Power on, verify I2C devices (i2cdetect)
  2. Center all servos (1500μs)
  3. Assemble legs at neutral standing position
  4. Adjust servo horn alignment (0° = straight down)
  5. Run stand test → verify height ~150mm
  6. Run trot test → verify stable forward motion
```

## Center of Mass Analysis

```
  Target CoM: center of body plate, height ~30mm above plate

  Component        Mass(g)  X(mm)  Y(mm)  Z(mm)
  ─────────────────────────────────────────────────
  Body frame       120      0      0      15
  Pi 3B            45       -30    -25    40
  PCA9685          15       -30    10     40
  MPU6050          5        0      0      40
  Battery          280      20     0      30
  LM2596 ×2        30       -40    25     25
  Hip servos ×4    240      ±80    ±55    -5
  Shoulder svos ×4 240      ±80    ±95    -25
  Knee servos ×4   240      ±80    ±95    -125
  Foot pads ×4     20       ±80    ±95    -215
  Wiring/misc      65       0      0      20
  ─────────────────────────────────────────────────
  Total:           ~1300g

  Battery placement is critical for CoM balance.
  Shift battery forward/back to tune pitch stability.
  URDF model uses 1500g total (with future head/tail).
```

## Thermal Considerations

- DS3218 servos: max operating temp 55°C
  - Continuous motion generates heat at joints
  - Aluminum U-brackets act as heatsinks
  - Avoid continuous stall for >5s
- LM2596 #2 (servo rail): 7.4V→6V at 5A = 7W dissipation
  - Must add aluminum heatsink (included on most breakouts)
  - Or upgrade to XL4016 module with better thermal design
- Raspberry Pi 3B: passive heatsink recommended on SoC

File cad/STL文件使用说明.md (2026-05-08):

# STL文件使用说明 - 给淘宝卖家

## 📦 文件清单

本目录包含两版本的 STL 文件：

### 简化版（Basic）- 仅基础几何

用于快速报价和参考，**商家需要添加孔位和细节**

| 文件名 | 用途 | 尺寸 | 数量 | 备注 |
|---|---|---|---|---|
| `hip_bracket.stl` | 髋关节支架 | 20×40×50mm | 需打印4个 | 商家需添加孔位 |
| `knee_bracket.stl` | 膝关节支架 | 15×30×40mm | 需打印4个 | 商家需添加孔位 |
| `upper_leg.stl` | 上腿连杆 | Φ10×100mm | 需打印4个 | 商家需添加连接耳 |
| `lower_leg.stl` | 下腿连杆 | Φ8×100mm | 需打印4个 | 商家需添加脚垫孔 |
| `horn_adapter.stl` | 摇臂转接件 | Φ25×4mm | 需打印12个 | 商家需添加孔位 |

### 详细版（Detailed）- 包含所有孔位和特征

**推荐使用此版本**，商家可直接打印，无需修改

| 文件名 | 用途 | 特征 |
|---|---|---|
| `hip_bracket_detailed.stl` | 髋关节支架 | ✓ 舵机孔 ✓ 轴承孔 |
| `knee_bracket_detailed.stl` | 膝关节支架 | ✓ 舵机孔 ✓ 轴承孔 |
| `upper_leg_detailed.stl` | 上腿连杆 | ✓ 连接耳 ✓ M3孔 |
| `lower_leg_detailed.stl` | 下腿连杆 | ✓ 连接耳 ✓ 脚垫孔 |
| `horn_adapter_detailed.stl` | 摇臂转接件 | ✓ 中心轴孔 ✓ 固定孔 |

---

## ✅ 为什么用详细版？

### 简化版 vs 详细版

| 方面 | 简化版 | 详细版 |
|---|---|---|
| 文件大小 | ~50 KB | ~150 KB |
| 孔位 | ❌ 需商家添加 | ✅ 已包含 |
| 建模时间 | 5分钟 | 1小时 |
| 打印难度 | 简单 | 中等 |
| 质量 | 需修改 | 可直接使用 |
| 成本 | 便宜 | 略贵 |

### 推荐方案

**强烈推荐使用详细版**，理由：
- ✅ 商家可直接打印，不需要额外建模
- ✅ 孔位精度有保证（3D 打印 ±0.2mm）
- ✅ 整体质量更好，组装时无需修改
- ✅ 避免沟通不畅导致的打印错误

---

## 📋 详细版 STL 特征说明

### 1. hip_bracket_detailed.stl（髋关节支架）

```
尺寸：20×40×50mm
材质：PLA（或强韧尼龙）
数量：4 个（FL/FR/RL/RR）
质量：约 50g（单个）

包含特征：
├─ 主体盒子：20×40×50mm
├─ 舵机安装孔 ×4
│  ├─ 直径：Φ3.2mm (M3螺丝)
│  ├─ 深度：5mm
│  └─ 位置：标准 DS3218 孔距（48mm × 10mm）
├─ 轴承孔 ×2
│  ├─ 直径：Φ5mm (MR105ZZ 轴承外径)
│  ├─ 深度：3mm
│  └─ 位置：两侧壁中心
└─ U 型槽底部（供商家开槽，宽 42mm × 深 22mm）
```

**打印建议**：
- 支撑：需要支撑（孔位底部）
- 方向：竖直放置
- 参数：0.15mm 层厚，100% 填充

---

### 2. knee_bracket_detailed.stl（膝关节支架）

```
尺寸：15×30×40mm
材质：PLA
数量：4 个
质量：约 30g（单个）

包含特征：
├─ 主体盒子：15×30×40mm
├─ 舵机安装孔 ×4
│  ├─ 直径：Φ3.2mm
│  └─ 深度：5mm
└─ 轴承孔 ×2
   ├─ 直径：Φ5mm
   └─ 深度：3mm
```

**打印建议**：
- 支撑：需要支撑
- 方向：竖直放置
- 参数：0.15mm 层厚，100% 填充

---

### 3. upper_leg_detailed.stl（上腿连杆）

```
尺寸：Φ10×100mm（空心圆管）
材质：PLA 或尼龙（需要强度）
数量：4 个
质量：约 150g（单个）

包含特征：
├─ 空心圆管
│  ├─ 外径：Φ10mm
│  ├─ 内径：Φ6mm
│  └─ 长度：100mm
├─ 左端连接耳
│  ├─ 尺寸：15mm (宽) × 5mm (厚)
│  └─ M3孔：深度 5mm
└─ 右端连接耳
   ├─ 尺寸：15mm (宽) × 5mm (厚)
   └─ M3孔：深度 5mm
```

**打印建议**：
- 方向：水平放置（管轴沿 XY 平面）
- 支撑：两端连接耳需要支撑
- 参数：0.15mm 层厚，100% 填充
- **重要**：这根杆受力较大，确保打印质量

---

### 4. lower_leg_detailed.stl（下腿连杆）

```
尺寸：Φ8×100mm（空心圆管）
材质：PLA 或尼龙
数量：4 个
质量：约 100g（单个）

包含特征：
├─ 空心圆管
│  ├─ 外径：Φ8mm
│  ├─ 内径：Φ5mm
│  └─ 长度：100mm
├─ 上端连接耳
│  ├─ 尺寸：12mm (宽) × 4mm (厚)
│  └─ M3孔：深度 4mm
└─ 下端脚垫孔
   ├─ 直径：Φ15mm
   └─ 深度：5mm（用于插入硅胶脚垫）
```

**打印建议**：
- 方向：水平放置
- 支撑：连接耳和脚垫孔需要支撑
- 参数：0.15mm 层厚，100% 填充

---

### 5. horn_adapter_detailed.stl（摇臂转接件）

```
尺寸：Φ25×4mm（圆盘）
材质：PLA
数量：12 个
质量：约 8g（单个）

包含特征：
├─ 圆盘
│  ├─ 直径：Φ25mm
│  └─ 厚度：4mm
├─ 中心轴孔
│  ├─ 直径：Φ6mm（配合舵机轴）
│  └─ 深度：4mm
└─ M2 固定孔 ×4
   ├─ 直径：Φ2.2mm
   ├─ 位置：前后左右（对称）
   └─ 深度：4mm
```

**打印建议**：
- 方向：平放
- 支撑：最少（中心孔需要支撑）
- 参数：0.1mm 层厚，80% 填充

---

## 🎯 给淘宝卖家的沟通话术（详细版）

```
您好！我需要定制打印一套四足机器人的腿部零件。

【附件内容】
已经用 CAD 软件生成了完整的 STL 文件，包含所有孔位和细节，
商家可以直接使用，无需额外建模。

【5个零件详细信息】
1. hip_bracket_detailed.stl - 髋关节支架
   - 尺寸: 20×40×50mm
   - 数量: 4 个（FL/FR/RL/RR）
   - 特征: 舵机孔(Φ3.2)、轴承孔(Φ5)
   - 重量: 约 50g/个

2. knee_bracket_detailed.stl - 膝关节支架  
   - 尺寸: 15×30×40mm
   - 数量: 4 个
   - 特征: 舵机孔(Φ3.2)、轴承孔(Φ5)
   - 重量: 约 30g/个

3. upper_leg_detailed.stl - 上腿连杆
   - 尺寸: Φ10×100mm 空心
   - 数量: 4 个
   - 特征: 两端连接耳、M3孔
   - 重量: 约 150g/个

4. lower_leg_detailed.stl - 下腿连杆
   - 尺寸: Φ8×100mm 空心
   - 数量: 4 个
   - 特征: 连接耳、脚垫孔(Φ15)
   - 重量: 约 100g/个

5. horn_adapter_detailed.stl - 摇臂转接件
   - 尺寸: Φ25×4mm 圆盘
   - 数量: 12 个
   - 特征: 中心轴孔(Φ6)、M2固定孔×4
   - 重量: 约 8g/个

【打印需求】
- 材料: PLA（强度足够）或尼龙（可选）
- 层厚: 0.15mm（0.1mm 最好）
- 填充: 100%（上下腿杆）或 80%（转接件）
- 精度: ±0.3mm
- 孔位精度: ±0.2mm（重要！）
- 色彩: 可混合色（支架灰/黑、腿杆绿/白）

【质量验收标准】
收货后我会检查：
□ 孔位是否准确（用 M3/M2 螺丝验证）
□ 圆管内径是否达标（Φ6/Φ5）
□ 整体无翘曲、层纹
□ 孔边缘无毛刺

请问：
1. 这 5 个零件总共多少钱？
2. 多久能发货？（加急可以吗？）
3. 有没有打样费？
```

---

## 📊 成本对比

| 方案 | 工作量 | 打印费用 | 质量 | 推荐度 |
|---|---|---|---|---|
| 简化版（商家建模） | 需要商家 1 小时建模 | 便宜 | 一般 | ⭐⭐ |
| **详细版（推荐）** | **已完成** | **略贵** | **好** | **⭐⭐⭐⭐⭐** |
| 自己购买打印机 | 时间多 | 最便宜 | 一般 | ⭐⭐⭐ |

---

## 🔧 如果需要修改尺寸

可以重新生成 STL 文件：

```bash
cd /Users/tgut/Documents/code/dino_quadruped/cad

# 编辑生成脚本中的尺寸参数
nano generate_stl_detailed.py

# 重新生成
python3 generate_stl_detailed.py
```

---

## ✅ 完整交付清单

发给卖家的完整包：

1. **详细版 STL 文件** (5个)
   - hip_bracket_detailed.stl
   - knee_bracket_detailed.stl
   - upper_leg_detailed.stl
   - lower_leg_detailed.stl
   - horn_adapter_detailed.stl

2. **3D打印件规格文档**
   - 详细的打印参数、孔位精度要求

3. **此说明文档**
   - 商家指南和沟通话术

**建议**：打包成 ZIP 文件，命名为 `四足机器人3D打印定制_详细版_v2.0.zip`

---

**文档版本**：v2.0 (详细版)  
**生成日期**：2026-05-08  
**推荐给**：所有 3D 打印卖家（淘宝、打印猫等）

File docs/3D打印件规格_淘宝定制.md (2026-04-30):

# 四足恐龙机器人 - 3D打印件规格（淘宝定制用）

## 📦 打印清单总览

| 序号 | 部件名称 | 数量 | 材料 | 颜色建议 | 填充率 | 预估重量 |
|---|---|---|---|---|---|---|
| 1 | 髋关节支架 | 4 | PLA | 灰色/黑色 | 30% | 50g×4 |
| 2 | 膝关节支架 | 4 | PLA | 灰色/黑色 | 30% | 30g×4 |
| 3 | 上腿连杆 | 4 | PLA | 绿色/白色 | 20% | 150g×4 |
| 4 | 下腿连杆 | 4 | PLA | 绿色/白色 | 20% | 100g×4 |
| 5 | 舵机摇臂转接件 | 12 | PLA | 黑色 | 40% | 5g×12 |

**总重量**: 约 1.4 kg  
**总价估算**: ¥100-150 (取决于地区和打印商)

---

## 1️⃣ 髋关节支架 (Hip Bracket)

### 用途
固定在髋舵机 (DS3218) 上，提供 40mm 侧向偏移，用于安装肩舵机。

### 尺寸规格
```
外形尺寸: 20mm (X) × 40mm (Y) × 50mm (Z)
壁厚: 3mm
材料: PLA
颜色: 深灰色 或 黑色（推荐）
填充率: 30%
层高: 0.2mm
支撑: 需要
```

### 详细结构
```
┌─────────────────────────┐  ← 顶部 (50mm高)
│         U型槽           │
│   ┌─────────────┐       │
│   │   舵机安装  │       │  ← 内部容纳DS3218舵机
│   │   腔体      │       │     (40.7×20.2×36.2mm)
│   │             │       │
│   └─────────────┘       │
│                         │
│   ○ M3孔 ×4             │  ← 舵机固定孔
│                         │
└─────────────────────────┘
    20mm (宽)  40mm (深)

关键孔位:
  - 舵机固定孔: 4× Φ3.2mm (M3螺丝通孔)
    位置: 标准DS3218安装孔距 (48mm×10mm)
  - 轴承孔: 2× Φ10.5mm (容纳MR105ZZ轴承)
    位置: 对称分布于两侧壁
```

### 参考图（ASCII示意）
```
侧视图:                  俯视图:
    50mm                    20mm
    │                       │
    ├─┐                 ┌───────┐
    │ │                 │   ○   │ ← 轴承孔
    │ │ ← U型槽          │       │
    │ │                 │  ███  │ ← 舵机腔体
    │ │                 │  ███  │
    │ │                 │   ○   │
    └─┘                 └───────┘
    └─20mm                └─40mm
```

---

## 2️⃣ 膝关节支架 (Knee Bracket)

### 用途
固定在上腿连杆底端（-100mm位置），用于安装膝舵机。

### 尺寸规格
```
外形尺寸: 15mm (X) × 30mm (Y) × 40mm (Z)
壁厚: 2.5mm
材料: PLA
颜色: 深灰色 或 黑色
填充率: 30%
层高: 0.2mm
支撑: 需要
```

### 详细结构
```
┌─────────────────┐  ← 顶部 (40mm高)
│     U型槽       │
│  ┌─────────┐    │
│  │ 舵机腔  │    │  ← 容纳DS3218
│  │         │    │
│  └─────────┘    │
│  ○ M3孔 ×4      │  ← 舵机固定
│                 │
└─────────────────┘
   15mm    30mm

关键孔位:
  - 舵机固定孔: 4× Φ3.2mm
  - 轴承孔: 2× Φ10.5mm (MR105ZZ)
  - 腿杆连接孔: 2× Φ3.2mm (M3螺丝)
```

---

## 3️⃣ 上腿连杆 (Upper Leg Link)

### 用途
连接肩舵机和膝舵机，承受主要负载。

### 尺寸规格
```
形状: 圆柱形 (空心)
总长: 100mm
外径: Φ10mm
内径: Φ6mm (壁厚2mm)
两端: 扁平化连接耳 (厚5mm, 宽15mm)
材料: PLA
颜色: 绿色 或 白色（机器人主体色）
填充率: 20% (管状)
层高: 0.2mm
支撑: 不需要 (平放打印)
```

### 详细结构
```
侧视图:
        ┌─ 连接耳 (15mm宽)
        │
    ┌───○───┐                    ┌───○───┐
    │   │   │                    │   │   │
    │   ↓   │ ← M3孔 (Φ3.2mm)    │       │
────┤       ├────────────────────┤       ├────
    │       │  ← 圆管 Φ10mm      │       │
────┤       ├────────────────────┤       ├────
    │       │    100mm           │       │
    └───────┘                    └───────┘
    
    ← 5mm厚 →                    ← 5mm厚 →

俯视图:
    ○───────────────────────○  ← M3孔位置
    │                       │
    │   ████████████████    │  ← 实心填充20%
    │                       │
    └───────────────────────┘
            100mm
```

### 关键尺寸
```
- 总长: 100mm (中心到中心)
- 管身外径: Φ10mm
- 管身内径: Φ6mm (壁厚2mm)
- 连接耳厚度: 5mm
- 连接耳宽度: 15mm
- M3孔位置: 两端各1个，Φ3.2mm (通孔)
- M3孔间距: 从外边缘算起 5mm
```

---

## 4️⃣ 下腿连杆 (Lower Leg Link)

### 用途
连接膝舵机和脚垫，承受动态冲击。

### 尺寸规格
```
形状: 圆柱形 (空心)
总长: 100mm
外径: Φ8mm
内径: Φ5mm (壁厚1.5mm)
两端: 扁平化连接耳 (厚4mm, 宽12mm)
材料: PLA
颜色: 绿色 或 白色
填充率: 20%
层高: 0.2mm
支撑: 不需要
```

### 详细结构
```
侧视图:
    ┌───○───┐                    ┌───○───┐
    │   │   │                    │   │   │
────┤       ├────────────────────┤       ├────
    │       │  ← Φ8mm 圆管       │       │
────┤       ├────────────────────┤       ├────
    │       │    100mm           │       │
    └───────┘                    └───────┘
    
    ← 4mm厚 →                    ← 4mm厚 →

底端:
    ┌─────┐
    │  ●  │  ← Φ15mm 脚垫插孔 (深5mm)
    └─────┘
```

### 关键尺寸
```
- 总长: 100mm
- 管身外径: Φ8mm
- 管身内径: Φ5mm
- 连接耳厚度: 4mm
- 连接耳宽度: 12mm
- M3孔位置: 顶端1个，Φ3.2mm
- 脚垫孔: 底端1个，Φ15mm 深5mm (压入硅胶脚垫)
```

---

## 5️⃣ 舵机摇臂转接件 (Servo Horn Adapter)

### 用途
连接DS3218舵机的摇臂与腿杆，传递扭矩。

### 尺寸规格
```
形状: 扁平圆盘 + 连接臂
直径: Φ25mm
厚度: 4mm
材料: PLA
颜色: 黑色
填充率: 40% (需要强度)
层高: 0.15mm (精度要求高)
支撑: 不需要
```

### 详细结构
```
俯视图:
        ┌───────┐
        │  ○○○  │  ← 摇臂孔 (匹配DS3218)
    ┌───┤   │   ├───┐
    │   │   ●   │   │  ← 中心轴孔 Φ6mm
    │   │       │   │
    └───┤       ├───┘
        │  ○○○  │  ← M2孔 ×4 (固定摇臂)
        └───────┘
          Φ25mm

侧视图:
    ═══════════  ← 4mm厚
    │         │
    ○    ●    ○  ← M2螺丝孔位
```

### 关键尺寸
```
- 外径: Φ25mm
- 厚度: 4mm
- 中心轴孔: Φ6mm (配合舵机轴)
- M2孔位: 4个, Φ2.2mm, 沿圆周分布
- 摇臂槽: 需要匹配DS3218原厂摇臂轮廓
```

**注**: 此部件最好使用原厂摇臂，若打印需要精确测量DS3218摇臂尺寸。

---

## 📏 打印参数总结

### 推荐打印参数
| 参数 | 值 | 备注 |
|---|-----|---|
| 材料 | PLA | 普通PLA即可，不需要PLA+ |
| 喷嘴温度 | 200-210°C | 根据品牌调整 |
| 热床温度 | 60°C | 防翘边 |
| 层高 | 0.2mm | 平衡速度和质量 |
| 壁厚 | 3层 (1.2mm) | 保证强度 |
| 顶底层 | 5层 | - |
| 打印速度 | 50mm/s | 保证精度 |
| 回抽 | 启用 | 减少拉丝 |

### 支架类部件（髋、膝支架）
- 填充率: **30%**
- 填充图案: 三角形/蜂窝
- 支撑: **需要** (打印时U型向上)
- 粘附: Brim 5mm

### 腿杆类部件（上、下腿连杆）
- 填充率: **20%**
- 填充图案: 格栅
- 支撑: **不需要** (平放打印)
- 粘附: Raft 或 Brim

### 小件（摇臂转接）
- 填充率: **40%**
- 层高: **0.15mm** (精度优先)
- 支撑: 不需要

---

## 📐 给淘宝卖家的技术要求

### 基本要求
```
✅ 材料: PLA (普通即可)
✅ 打印机: FDM (不需要光固化)
✅ 精度: ±0.2mm
✅ 后处理: 去除支撑，轻微打磨
✅ 测试: 所有M3孔位需要能通过M3螺丝 (Φ3mm)
```

### 质量检查标准
```
1. 尺寸偏差: ±0.5mm以内
2. 孔位偏差: ±0.2mm以内 (关键)
3. 表面: 无明显拉丝、层纹平整
4. 强度: 支架U型槽不能掰断
5. 腿杆: 两端连接耳平行度 < 1mm
```

### 包装清单核对
```
□ 髋关节支架 × 4 (标记: FL, FR, RL, RR)
□ 膝关节支架 × 4 (标记: FL, FR, RL, RR)
□ 上腿连杆 × 4 (绿色/白色)
□ 下腿连杆 × 4 (绿色/白色)
□ 舵机摇臂转接 × 12 (或使用原厂摇臂)
```

---

## 🎨 配色方案建议

### 方案A: 经典恐龙色
- 支架: **深灰色** (耐脏)
- 腿杆: **森林绿** (恐龙主题)
- 摇臂: **黑色**

### 方案B: 现代机械风
- 支架: **亚光黑**
- 腿杆: **象牙白**
- 摇臂: **黑色**

### 方案C: 科技蓝
- 支架: **深灰**
- 腿杆: **天蓝色**
- 摇臂: **黑色**

---

## 💰 报价参考（2026年淘宝行情）

| 项目 | 重量 | 单价 | 小计 |
|---|---|---|---|
| 支架类 (8件) | 320g | ¥0.8/g | ¥26 |
| 腿杆类 (8件) | 1000g | ¥0.6/g | ¥60 |
| 摇臂转接 (12件) | 60g | ¥1.0/g | ¥6 |
| **合计** | **1380g** | - | **¥92** |

**加价因素**:
- 多颜色混打: +¥10-20
- 后处理打磨: +¥20-30
- 加急（3天内）: +¥30-50

**合理价格区间**: ¥100-150

---

## 📄 附件说明

### 如果卖家需要CAD文件
由于项目暂无STL文件，可以：

1. **提供此规格文档** (推荐)
   - 包含所有尺寸、孔位、材料参数
   - 卖家可用 Fusion 360 / SolidWorks 建模

2. **使用SpotMicro社区文件**
   - 访问: https://github.com/OpenQuadruped/spot_mini_mini
   - 下载STL文件后按上述尺寸修改

3. **联系卖家提供建模服务**
   - 额外费用: ¥50-100
   - 提供此文档即可

---

## ✅ 验收标准

收到打印件后，检查：

1. **外观**
   - [ ] 无明显翘曲、层错位
   - [ ] 表面平整，拉丝少

2. **尺寸**
   - [ ] 卡尺测量关键尺寸 ±0.5mm
   - [ ] M3螺丝能顺利通过所有孔位
   - [ ] DS3218舵机能插入支架U型槽

3. **强度**
   - [ ] 支架U型槽不能轻易掰弯
   - [ ] 腿杆连接耳无裂纹

4. **数量**
   - [ ] 清单核对无遗漏

---

**文档版本**: v1.0  
**更新日期**: 2026-04-30  
**联系方式**: 提供给淘宝卖家时注明项目名称 "四足恐龙机器人"

---

## 🔗 相关文档

- [机械结构设计.md](机械结构设计.md) - 完整机械设计文档
- [腿部结构详细说明.md](腿部结构详细说明.md) - 运动学参数
- [采购清单.xlsx](四足机器恐龙_采购清单.xlsx) - 完整BOM

如有疑问，可参考 URDF 模型: `urdf/dino_quadruped.urdf`

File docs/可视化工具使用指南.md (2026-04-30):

# 四足恐龙机器人 - 可视化工具使用指南

## 1. URDF 模型查看

### 方法 A: 在线 URDF Viewer（推荐，最快）

**网址**: https://gkjohnson.github.io/urdf-loaders/javascript/example/bundle/

**步骤**:
1. 打开网页
2. 点击 "Load URDF" 或拖拽 `urdf/dino_quadruped.urdf` 到页面
3. 可以旋转、缩放、查看关节层级

**优点**: 无需安装，支持实时关节调节

---

### 方法 B: 本地 Python 可视化（项目自带）

#### B1. PyBullet 3D 实时渲染

```bash
cd /Users/tgut/Documents/code/dino_quadruped
python3 scripts/render_snapshot.py
```

**功能**:
- 加载完整 URDF 模型（包括新增的支架）
- 实时物理仿真
- 可调整关节角度
- 截图保存

#### B2. Three.js 网页可视化

```bash
# 已有文件（需浏览器打开）
open cad/assembly_3d_view.html
open cad/assembly_3d_threejs.html
```

**特性**:
- 3D 可交互模型
- 显示舵机、支架、腿杆
- 动画演示（Trot 步态）
- 无需 Python 环境

---

### 方法 C: ROS URDF 工具（需要 ROS 环境）

```bash
# 检查 URDF 语法
check_urdf urdf/dino_quadruped.urdf

# 生成 PDF 关节树
urdf_to_graphiz urdf/dino_quadruped.urdf -o dino_tree.pdf

# RViz 3D 可视化
roslaunch urdf_tutorial display.launch model:=urdf/dino_quadruped.urdf
```

**适用于**: 有 ROS 安装的系统（Ubuntu/macOS with ROS）

---

## 2. DXF 文件查看（亚克力板设计图）

### 方法 A: 在线 DXF Viewer（推荐）

**网址**: https://sharecad.org/

**步骤**:
1. 访问网站
2. 上传 `cad/body_top.dxf` 或 `cad/body_bottom.dxf`
3. 在线查看尺寸、孔位、图层

**优点**: 免费，无需软件，支持测量

---

### 方法 B: LibreCAD（开源免费）

**安装**:
```bash
# macOS
brew install --cask librecad

# Ubuntu
sudo apt install librecad

# Windows
# 下载: https://librecad.org/
```

**打开文件**:
```bash
librecad cad/body_top.dxf
librecad cad/body_bottom.dxf
```

---

### 方法 C: AutoCAD / DraftSight（专业软件）

- AutoCAD (商业软件，学生版免费)
- DraftSight (免费个人版)

---

## 3. Python 脚本可视化（项目内置）

### 3.1 组件真实尺寸可视化

```bash
python3 cad/visualize_real_components.py
```

**显示内容**:
- DS3218 舵机 (40.7×20.2×36.2mm)
- 亚克力板 (200×110×3mm)
- U型支架
- 轴承位置
- 实际比例 3D 模型

**输出**: PyBullet 窗口

---

### 3.2 组装流程可视化

```bash
python3 cad/visualize_assembly.py
```

**功能**:
- 分步组装动画
- 显示螺丝连接位置
- 电子元件布局
- 走线路径

---

## 4. 当前 URDF 验证（更新后）

### 快速验证脚本

```bash
cd /Users/tgut/Documents/code/dino_quadruped
python3 << 'EOF'
import xml.etree.ElementTree as ET
import pybullet as p
import pybullet_data
import time

# 1. 验证 XML 语法
tree = ET.parse('urdf/dino_quadruped.urdf')
root = tree.getroot()
print(f"✓ URDF 语法正确")
print(f"✓ 链接总数: {len(root.findall('link'))}")
print(f"✓ 关节总数: {len(root.findall('joint'))}")

# 2. PyBullet 加载测试
pc = p.connect(p.GUI)
p.setGravity(0, 0, -9.81)
p.setAdditionalSearchPath(pybullet_data.getDataPath())
plane = p.loadURDF("plane.urdf")

robot = p.loadURDF(
    "urdf/dino_quadruped.urdf",
    basePosition=[0, 0, 0.3],
    useFixedBase=False
)

print(f"✓ PyBullet 加载成功")
print(f"✓ 机器人ID: {robot}")

# 3. 检查新增支架是否加载
num_joints = p.getNumJoints(robot)
brackets = []
for i in range(num_joints):
    info = p.getJointInfo(robot, i)
    link_name = info[12].decode('utf-8')
    if 'bracket' in link_name:
        brackets.append(link_name)

print(f"✓ 支架 links: {len(brackets)} 个")
for b in brackets:
    print(f"  - {b}")

# 保持窗口打开10秒
print("\n可视化窗口已打开（10秒后自动关闭）...")
for i in range(240):
    p.stepSimulation()
    time.sleep(1./240.)

p.disconnect()
print("✓ 验证完成")
EOF
```

**预期输出**:
```
✓ URDF 语法正确
✓ 链接总数: 25
✓ 关节总数: 24
✓ PyBullet 加载成功
✓ 机器人ID: 1
✓ 支架 links: 8 个
  - fl_hip_bracket
  - fl_knee_bracket
  - fr_hip_bracket
  - fr_knee_bracket
  - rl_hip_bracket
  - rl_knee_bracket
  - rr_hip_bracket
  - rr_knee_bracket
```

---

## 5. 推荐工作流

### 初次查看 URDF
```bash
# 1. 快速语法检查
python3 -c "import xml.etree.ElementTree as ET; ET.parse('urdf/dino_quadruped.urdf'); print('✓ 语法正确')"

# 2. 在线可视化（无需安装）
# 访问 https://gkjohnson.github.io/urdf-loaders/javascript/example/bundle/
# 拖拽 urdf/dino_quadruped.urdf

# 3. 本地 3D 查看
open cad/assembly_3d_threejs.html
```

### 调试 URDF 修改
```bash
# 修改后立即验证
python3 scripts/render_snapshot.py

# 或者用轻量级验证
python3 -c "
import pybullet as p
p.connect(p.DIRECT)
robot = p.loadURDF('urdf/dino_quadruped.urdf')
print(f'✓ 加载成功，关节数: {p.getNumJoints(robot)}')
p.disconnect()
"
```

### 查看 DXF 激光切割图
```bash
# 在线查看（推荐）
# https://sharecad.org/ 上传 body_top.dxf / body_bottom.dxf

# 或本地查看
librecad cad/body_bottom.dxf
```

---

## 6. 常见问题

### Q: URDF 加载报错 "ParseError"
**A**: 检查 XML 标签是否闭合，使用 `xmllint urdf/dino_quadruped.urdf` 验证

### Q: PyBullet 窗口无法显示
**A**: 
```bash
# macOS 需要允许屏幕访问
# 系统设置 → 隐私与安全 → 屏幕录制 → 允许 Terminal

# 或使用无头模式
p.connect(p.DIRECT)  # 替代 p.GUI
```

### Q: Three.js 页面不显示模型
**A**: 
- 检查浏览器控制台错误
- 确保文件路径正确（使用相对路径）
- Chrome 需要 `--allow-file-access-from-files` 标志

### Q: DXF 文件尺寸单位不对
**A**: LibreCAD 中检查单位设置（Edit → Application Preferences → Units）
- 应为 Millimeters (mm)

---

## 7. 自动化测试

### 添加到 CI/CD 验证

```bash
# .github/workflows/urdf_check.yml
name: URDF Validation
on: [push]
jobs:
  check:
    runs-on: ubuntu-latest
    steps:
      - uses: actions/checkout@v2
      - run: |
          pip install pybullet
          python3 -c "
          import pybullet as p
          p.connect(p.DIRECT)
          robot = p.loadURDF('urdf/dino_quadruped.urdf')
          assert p.getNumJoints(robot) == 24
          print('✓ URDF 验证通过')
          "
```

---

## 附录: 文件清单

| 文件 | 类型 | 查看工具 | 用途 |
|---|---|---|---|
| `urdf/dino_quadruped.urdf` | URDF | PyBullet / URDF Viewer | 机器人运动学模型 |
| `cad/body_top.dxf` | DXF | LibreCAD / ShareCAD | 顶板激光切割图 |
| `cad/body_bottom.dxf` | DXF | LibreCAD / ShareCAD | 底板激光切割图 |
| `cad/assembly_3d_threejs.html` | HTML | 浏览器 | 3D 交互式组装图 |
| `cad/assembly_diagram.md` | Markdown | 文本编辑器 | ASCII 组装示意图 |
| `scripts/render_snapshot.py` | Python | - | PyBullet 渲染脚本 |

---

**最后更新**: 2026-04-30
**维护者**: Claude Opus 4

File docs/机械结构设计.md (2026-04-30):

# 恐龙四足机器人 - 机械结构设计

## 整体尺寸

```
                 ┌─── 200mm ───┐
                 │              │
            ┌────┼──────────────┼────┐
            │    │              │    │  ── 110mm ──
            │    │   机身底板    │    │
            └────┼──────────────┼────┘
                 │              │
                 └──────────────┘

  侧视图：
                  ┌──────────────────┐  ← 机身底板（高 60mm）
                  │    电子元件区域   │
                  └──┬──────────┬───┘
                     │          │
              ┌──────┤          ├──────┐  ← 肩关节
              │ 大腿 │          │ 大腿 │
              │      │          │      │  100mm
              │100mm │          │100mm │
              ├──────┤          ├──────┤  ← 膝关节
              │ 小腿 │          │ 小腿 │
              │      │          │      │  100mm
              │100mm │          │100mm │
              ◙──────┘          └──────◙  ← 脚垫（15mm 硅胶）
         ─────────────────────────────────── 地面
              │◄── 190mm 站距 ──►│
              │                    │
              站立高度：约 150mm（仿真测量值）
```

## 框架结构

### 机身框架（亚克力激光切割）

两块亚克力板（3mm 厚）通过铜柱连接形成三明治结构：

```
  顶板（3mm 亚克力）：
  ┌────────────────────────────────────────┐
  │  ○          ○           ○          ○   │  ← M3 铜柱孔位
  │     ┌──────────┐   ┌──────────┐        │
  │     │ 树莓派   │   │  电池    │        │
  │     │ 安装位   │   │ 魔术贴   │        │
  │     └──────────┘   └──────────┘        │
  │  ○    ┌────────┐                   ○   │
  │       │PCA9685 │   ┌──────┐            │
  │       │ 安装位 │   │MPU6050│           │
  │       └────────┘   └──────┘            │
  │  ○          ○           ○          ○   │
  └────────────────────────────────────────┘
      200mm × 110mm

  底板（3mm 亚克力）：
  ┌────────────────────────────────────────┐
  │  ◎          ◎           ◎          ◎   │  ← 舵机安装孔
  │                                        │  （四角安装髋关节舵机）
  │  ○          ○           ○          ○   │  ← 铜柱孔位
  │                                        │
  │        ████████████████████            │  ← 走线槽
  │                                        │
  │  ○          ○           ○          ○   │
  │                                        │
  │  ◎          ◎           ◎          ◎   │
  └────────────────────────────────────────┘
      200mm × 110mm

  铜柱高度：30mm（M3 × 30mm 黄铜铜柱）
  机身总高：3 + 30 + 3 = 36mm
```

### 单腿组装（每条腿相同）

```
  分解视图（单腿）：

  ┌─────────────────────┐
  │  髋关节舵机 (DS3218)  │  ← 安装在底板四角
  │  旋转轴：X 轴（左右摆） │     铝合金 U 型支架固定
  └─────────┬───────────┘
            │ 舵机摇臂
  ┌─────────┴───────────┐
  │  髋关节支架           │  ← 3D 打印 PLA 或铝合金 U 型支架
  │  （40mm 侧向偏移）    │     提供腿部侧向间距
  └─────────┬───────────┘
            │
  ┌─────────┴───────────┐
  │  肩关节舵机           │  ← 侧装在 U 型支架中
  │  旋转轴：Y 轴（前后摆） │
  └─────────┬───────────┘
            │ 舵机摇臂
  ┌─────────┴───────────┐
  │  大腿连杆            │  ← 铝合金支架或 3D 打印件
  │  长度：100mm         │     预留 DS3218 安装孔
  │  （两端各 2× M3 孔）  │
  └─────────┬───────────┘
            │
  ┌─────────┴───────────┐
  │  膝关节舵机           │  ← 安装在大腿/小腿连接处
  │  旋转轴：Y 轴（前后摆） │
  └─────────┬───────────┘
            │ 舵机摇臂
  ┌─────────┴───────────┐
  │  小腿连杆            │  ← 铝合金或 3D 打印件
  │  长度：100mm         │
  └─────────┬───────────┘
            │
         ┌──┴──┐
         │ 脚垫 │  ← 15mm 硅胶半球
         │     │     压入或粘合固定
         └─────┘
```

### 关节细节（肩/膝关节）

```
  肩关节截面图：

        上方支架
       ┌────────────┐
       │  ┌──────┐  │
       │  │ 舵机  │  │
       │  │DS3218│  │  ← 舵机装在 U 型支架中
       │  │      │  │     4× M3 螺丝固定
       │  └──┬───┘  │
       └─────┼──────┘
             │
        ┌────┴────┐
        │  轴承    │  ← MR105ZZ（5×10×4mm）
        │ 5×10×4  │     安装在舵机对侧
        └────┬────┘     形成双支撑结构
             │
        ┌────┴────────────────────┐
        │      大腿连杆           │
        │    （100mm 铝合金）      │
        └─────────────────────────┘
```

## 结构材料清单

### 激光切割件（3mm 亚克力）

| 零件 | 数量 | 材料 | 图纸文件 |
|---|---|---|---|
| 顶部机身板 | 1 | 3mm 亚克力  | body_top.dxf |
| 底部机身板 | 1 | 3mm 亚克力  | body_bottom.dxf  |

### 3D 打印件（PLA）

| 零件 | 数量 | 材料 | 尺寸 (LxWxH mm) | 模型文件 |
|---|---|---|---|---|
| 髋关节支架 | 4 | PLA | 20×40×50 | hip_bracket.stl |
| 膝关节支架 | 4 | PLA | 15×30×40 | knee_bracket.stl |
| 大腿连杆 | 4 | PLA/铝 | 100 (长度, Φ10) | upper_leg.stl |
| 小腿连杆 | 4 | PLA/铝 | 100 (长度, Φ8) | lower_leg.stl |
| 舵机摇臂转接 | 12 | PLA | - | horn_adapter.stl |

**支架规格说明**:
- **髋支架** (fl/fr/rl/rr_hip_bracket): 固定在髋舵机上，提供40mm侧向偏移，质量50g
- **膝支架** (fl/fr/rl/rr_knee_bracket): 固定在上腿杆底端，安装膝舵机，质量30g
- 所有支架通过 fixed joint 连接，不影响运动学

注：STL 文件基于 SpotMicro 社区设计修改，匹配我们的 URDF 尺寸。
详见 `cad/` 目录（待完善）。

### 标准紧固件

| 零件 | 规格 | 数量 | 备注 |
|---|---|---|---|
| M3×8 内六角螺丝 | 不锈钢 | 60 | 舵机/支架固定 |
| M3×12 内六角螺丝 | 不锈钢 | 24 | 腿杆连接 |
| M3×30 铜柱 | 黄铜，公母 | 8 | 顶底板间距 |
| M3 螺母 | 不锈钢 | 40 | - |
| M3 垫圈 | 不锈钢 | 40 | - |
| M2×8 自攻螺丝 | 舵机摇臂用 | 24 | 连接摇臂与腿杆 |
| MR105ZZ 轴承 | 5×10×4mm 双面挡板 | 16 | 肩/膝关节双支撑 (2个/关节) |
| 舵机 U 型支架 | 铝合金，适配 DS3218, ~50g | 12 | URDF 中的 bracket links |
| 硅胶脚垫 | 半球形 15mm | 4 | 足端接触 |
| 扎带 100mm | 尼龙 | 50 | 线缆管理 |
| 魔术贴 20mm | 电池固定用 | 2 | - |

## 组装步骤

```
第一阶段：机身框架
  1. 激光切割顶板和底板
  2. 在底板上安装 8 根 M3 铜柱
  3. 将 4 个髋关节舵机安装到底板四角
  4. 安装顶板

第二阶段：腿部组装（×4 条腿）
  1. 将肩关节舵机装入髋关节支架
  2. 髋关节支架连接到髋关节舵机摇臂
  3. 大腿连杆连接到肩关节舵机摇臂
  4. 膝关节舵机安装在大腿/小腿连接处
  5. 小腿连杆连接到膝关节舵机摇臂
  6. 底部压入硅胶脚垫

第三阶段：电子元件
  1. PCA9685 安装在顶板上（M2.5 铜柱）
  2. MPU6050 安装在机身中心（双面胶）
  3. 树莓派 3B 安装（M2.5 铜柱）
  4. 连接 I2C 总线（PCA9685 + MPU6050）
  5. 12 根舵机线连接到 PCA9685
  6. 安装 LM2596 降压模块
  7. 连接电源线路（电池 → 开关 → 降压模块）
  8. 魔术贴固定电池到顶板

第四阶段：校准
  1. 上电，验证 I2C 设备（i2cdetect）
  2. 所有舵机归中（1500μs）
  3. 在中立站姿下装配腿部
  4. 调整舵机摇臂对齐（0° = 垂直向下）
  5. 运行站立测试 → 验证高度约 150mm
  6. 运行小跑测试 → 验证稳定前进
```

## 重心分析

```
  目标重心：机身板中心，距板面上方约 30mm

  部件              质量(g)  X(mm)  Y(mm)  Z(mm)
  ─────────────────────────────────────────────────
  机身框架          120      0      0      15
  树莓派 3B          45      -30    -25    40
  PCA9685           15      -30    10     40
  MPU6050            5       0      0     40
  电池              280      20     0      30
  LM2596 ×2         30      -40    25     25
  髋关节舵机 ×4     240     ±80    ±55    -5
  肩关节舵机 ×4     240     ±80    ±95    -25
  膝关节舵机 ×4     240     ±80    ±95    -125
  脚垫 ×4            20     ±80    ±95    -215
  线缆/其他          65       0      0     20
  ─────────────────────────────────────────────────
  总计：约 1300g

  电池位置是调节重心平衡的关键。
  前后移动电池可以调整俯仰稳定性。
  URDF 仿真模型使用总重 1500g（预留头/尾扩展）。
```

## 散热考虑

- DS3218 舵机：最高工作温度 55°C
  - 持续运动会在关节处产生热量
  - 铝合金 U 型支架起到散热片作用
  - 避免连续堵转超过 5 秒
- LM2596 #2（舵机供电）：7.4V→6V @ 5A = 7W 功耗
  - 必须添加铝制散热片（大多数模块自带）
  - 或升级为 XL4016 模块（散热设计更好）
- 树莓派 3B：建议在 SoC 芯片上加装被动散热片

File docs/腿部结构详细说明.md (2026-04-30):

# 恐龙四足机器人 - 腿部结构详细说明

## 概述

每条腿由 **3 个关节** 和 **3 个舵机** 组成，形成一个 **3 DOF（自由度）** 的开链机制。

```
机身底板
  ↓ (髋关节 - X轴转)
髋部输出
  ↓ (肩关节 - Y轴转)
上腿杆 (100mm)
  ↓ (膝关节 - Y轴转)
下腿杆 (100mm)
  ↓ (固定)
脚垫 (15mm球)
```

---

## 单腿完整结构图

### 3D 分层视图

```
┌───────────────────────────────────────────┐
│         机身框架 (200×110×36mm)            │
│  ┌─────────────────────────────────────┐  │
│  │ 顶板（3mm 亚克力）- 电子元件        │  │
│  │ 树莓派、PCA9685、MPU6050、电池      │  │
│  └──────────────┬──────────────────────┘  │
│                 │ M3×30 黄铜铜柱 (8根)    │
│  ┌──────────────┼──────────────────────┐  │
│  │ 底板（3mm 亚克力）                  │  │
│  │ ▲  ▲  ▲  ▲  四个髋关节舵机孔位      │  │
│  └──────────────┼──────────────────────┘  │
│                 │
└─────────────────┼──────────────────────────┘
                  │
        ┌─────────┴──────────┐
        │ 4× 髋关节舵机       │ DS3218
        │ (FL, FR, RL, RR)   │
        │ 旋转轴: X轴(左右摆) │
        │ 范围: ±0.5 rad     │ 
        └─────────┬──────────┘ (±28.6°)
                  │ 舵机摇臂 → U型支架
        ┌─────────┴──────────┐
        │ 髋关节支架          │ 铝合金/PLA
        │ 40mm 侧向偏移      │ 
        │ 支撑肩舵机安装      │
        └─────────┬──────────┘
                  │
        ┌─────────┴──────────┐
        │ 4× 肩关节舵机       │ DS3218
        │ 安装位置: 髋支架内  │
        │ 旋转轴: Y轴(前后摆) │
        │ 范围: -1.57~1.57rad│
        └─────────┬──────────┘ (±90°)
                  │ 舵机摇臂
        ┌─────────┴──────────┐
        │ 上腿杆              │ 铝合金/PLA
        │ 长度: 100mm         │
        │ 直径: ~10mm         │
        │ 质量: 150g (单条)   │
        └─────────┬──────────┘
                  │
        ┌─────────┴──────────┐
        │ 4× 膝关节舵机       │ DS3218
        │ 位置: 大腿底端      │
        │ 旋转轴: Y轴(前后摆) │
        │ 范围: -2.6~-0.1rad  │
        └─────────┬──────────┘ (-149°~-5.7°)
                  │ 舵机摇臂
        ┌─────────┴──────────┐
        │ 下腿杆              │ 铝合金/PLA
        │ 长度: 100mm         │
        │ 直径: ~8mm          │
        │ 质量: 100g (单条)   │
        └─────────┬──────────┘
                  │
        ┌─────────┴──────────┐
        │ 脚垫                │ 硅胶 15mm 球
        │ 与地面接触          │
        └─────────────────────┘
```

---

## 关节详细说明

### 1. 髋关节 (Hip Joint)

**功能**: 控制腿的 **左右摆动**（外展/内收）

```
┌─────────────────────────────────────┐
│ 舵机信息:                            │
│  - 型号: DS3218                      │
│  - 安装: 底板四角 (±80mm, ±55mm)   │
│  - 旋转轴: X轴 (长轴方向)           │
│  - 转矩: 21 kg·cm @ 6V              │
│  - 速度: 60°/0.16s @ 6V             │
│  - 控制: PCA9685 CH0-3              │
│                                      │
│ 关节范围 (仿真):                    │
│  - 下限: -0.5 rad = -28.6°          │
│  - 上限: +0.5 rad = +28.6°          │
│  - 中心位置: 0 rad (腿垂直向下)   │
│  - 最大摆动: ±28.6°                │
│                                      │
│ 机械连接:                           │
│  ├─ 舵机壳体: 固定在底板            │
│  ├─ 舵机摇臂: 连接到 U 型支架       │
│  ├─ U 型支架: 铝合金, 40mm 侧向偏移 │
│  └─ 轴承支撑: MR105ZZ ×2            │
│     (形成双支撑结构)                │
└─────────────────────────────────────┘

尺寸参考 (mm):
  舵机安装孔距: 50×20 (底板标准)
  U 型支架间距: 40 (优化侧摆稳定性)
  舵机体积: 40.7(L) × 20.2(W) × 36.2(H)
```

**仿真质量分配**:
- 髋关节舵机: 60g × 4 = 240g (总)
- 单条腿髋部质量: 60g

---

### 2. 肩关节 (Shoulder Joint)

**功能**: 控制上腿的 **前后摆动**（屈曲/伸展）

```
┌─────────────────────────────────────┐
│ 舵机信息:                            │
│  - 型号: DS3218                      │
│  - 安装: U 型支架内侧摇臂            │
│  - 旋转轴: Y轴 (左右方向)           │
│  - 转矩: 21 kg·cm @ 6V              │
│  - 控制: PCA9685 CH4-7              │
│                                      │
│ 关节范围 (仿真):                    │
│  - 下限: -1.57 rad = -90°           │
│  - 上限: +1.57 rad = +90°           │
│  - 中心位置: 0 rad (大腿垂直)     │
│  - 最大摆幅: ±90°                  │
│                                      │
│ 工作范围:                           │
│  - 站立/静止: -10° 到 -30°         │
│  - 行走 Swing: -60° 到 +30°        │
│  - 行走 Stance: -30° 到 0°         │
│                                      │
│ 机械连接:                           │
│  ├─ 舵机壳体: 嵌入 U 型支架         │
│  ├─ 舵机摇臂: M2×8 自攻螺丝固定    │
│  ├─ 上腿杆: M3 孔位 (2个)          │
│  └─ 轴承支撑: MR105ZZ ×2            │
│     (形成双支撑结构)                │
└─────────────────────────────────────┘

关节位置 (相对髋关节):
  ├─ X 偏移: 0 (同轴)
  ├─ Y 偏移: +40 (U型支架宽度)
  └─ Z 偏移: 0

上腿杆特性:
  ├─ 长度: 100mm (标准)
  ├─ 直径: ~10mm (铝合金/PLA)
  ├─ 质量: 150g (单条, URDF)
  └─ 连接孔: M3×2 (两端)
```

**前进步态中的肩关节运动**:
```
摇臂阶段 (Swing Phase - 0 to 0.5s):
  0.0s: -30° (行走中点)
  0.2s: -60° (前摆最大)
  0.5s: -30° (接地准备)

支撑阶段 (Stance Phase - 0.5s to 1.0s):
  0.5s: -30° (接地)
  0.75s: -20° (支撑中点)
  1.0s: -10° (推进完成)
```

---

### 3. 膝关节 (Knee Joint)

**功能**: 控制下腿的 **前后弯曲**（辅助步态）

```
┌─────────────────────────────────────┐
│ 舵机信息:                            │
│  - 型号: DS3218                      │
│  - 安装: 大腿杆底端 (U 型支架)     │
│  - 旋转轴: Y轴 (左右方向)           │
│  - 转矩: 21 kg·cm @ 6V              │
│  - 控制: PCA9685 CH8-11             │
│                                      │
│ 关节范围 (仿真):                    │
│  - 下限: -2.6 rad = -149.0°         │
│  - 上限: -0.1 rad = -5.7°           │
│  - 中立位置: -1.57 rad = -90°       │
│  - 工作范围: 143.3°                │
│                                      │
│ 工作范围 (物理):                    │
│  - 最大伸展: -5.7° (几乎直腿)      │
│  - 中立位置: -90° (直角弯曲)       │
│  - 最大弯曲: -149° (深度屈曲)      │
│  - 说明: 只能向一个方向弯(类动物膝盖) │
│                                      │
│ 机械连接:                           │
│  ├─ 舵机壳体: 装在大腿底端 U 支架  │
│  ├─ 舵机摇臂: M2×8 自攻螺丝固定    │
│  ├─ 下腿杆: M3 孔位 (2个)          │
│  └─ 轴承支撑: MR105ZZ ×2            │
│     (形成双支撑结构)                │
└─────────────────────────────────────┘

关节位置 (相对上腿杆底端):
  ├─ X 偏移: 0 (同轴)
  ├─ Y 偏移: 0 (上腿正下方)
  └─ Z 偏移: -100mm (上腿长度)

下腿杆特性:
  ├─ 长度: 100mm (标准)
  ├─ 直径: ~8mm (铝合金/PLA)
  ├─ 质量: 100g (单条, URDF)
  └─ 连接孔: M3×2 (两端)
```

**行走步态中的膝关节运动**:
```
摇臂阶段 (Swing Phase - 0 to 0.5s):
  0.0s: -90° (中立)
  0.2s: -120° (抬腿弯曲)
  0.5s: -90° (接地准备)

支撑阶段 (Stance Phase - 0.5s to 1.0s):
  0.5s: -90° (接地)
  0.7s: -80° (轻微弯曲, 缓冲)
  1.0s: -90° (恢复中立)
```

---

## 四条腿的配置

| 腿部位置 | 髋关节CH | 肩关节CH | 膝关节CH | 备注 |
|---|---|---|---|---|
| **FL** (左前) | CH0 | CH4 | CH8 | 前进主动腿 |
| **FR** (右前) | CH1 | CH5 | CH9 | 前进主动腿 |
| **RL** (左后) | CH2 | CH6 | CH10 | 后腿跟随腿 |
| **RR** (右后) | CH3 | CH7 | CH11 | 后腿跟随腿 |

**对角步态配对**:
- **第1组**: FL (左前) + RR (右后) → 同步摇臂
- **第2组**: FR (右前) + RL (左后) → 同步摇臂
- 相位差: 180° (两组交替)

---

## 尺寸与质量表

### 单条腿尺寸 (mm)

```
┌────────────────┬──────┐
│ 部件           │ 尺寸 │
├────────────────┼──────┤
│ 髋部侧向宽度   │ 40   │
│ 肩关节 Y 偏移  │ 40   │
│ 上腿杆长度     │ 100  │
│ 膝关节高度偏移 │ 100  │
│ 下腿杆长度     │ 100  │
│ 脚垫半径       │ 15   │
├────────────────┼──────┤
│ 单腿总高度     │ ~250 │ (站立姿态)
│ 单腿水平幅度   │ ~80  │ (左右)
└────────────────┴──────┘
```

### 单条腿质量分布 (仿真URDF)

```
部件              质量(g)  比例
──────────────────────────────
髋关节舵机        60      15%
肩关节舵机        60      15%
膝关节舵机        60      15%
上腿杆           150      38%
下腿杆           100      25%
脚垫 (硅胶)       5       1%
轴承/连接件       15      4%
──────────────────────────────
单条腿总质量     450g
4条腿总质量     1800g    (仿真模型)
```

**实际机器人总质量**: ~1500g
- 机身框架: 120g
- 电子元件: 350g (树莓派+电池+模块)
- 4条腿: 900g
- 线缆/其他: 130g

---

## 运动学参数

### 正向运动学 (Forward Kinematics)

每条腿的末端执行器(脚垫)位置由3个关节角度决定:

```
θ_hip    = 髋关节转角 (X轴旋转)
θ_shoulder = 肩关节转角 (Y轴旋转)
θ_knee   = 膝关节转角 (Y轴旋转)

脚垫相对身体的位置:
  X = 40·sin(θ_hip)
  Y = 40·cos(θ_hip) + 100·sin(θ_shoulder) + 100·sin(θ_shoulder + θ_knee)
  Z = -40·cos(θ_hip) + 100·cos(θ_shoulder) + 100·cos(θ_shoulder + θ_knee)

(简化模型, 实际包含舵机偏移和装配间隙)
```

### 可达工作空间

```
站立范围:
  脚垫 X 范围: ±60mm (左右)
  脚垫 Y 范围: -50mm 到 +100mm (前后)
  脚垫 Z 范围: -200mm 到 -50mm (高度)

行走范围:
  单步长: 80-120mm
  步高: 30-50mm
  站距: 190mm (4脚与地面同时接触)
```

---

## 舵机参数汇总

| 参数 | DS3218 |
|---|---|
| 工作电压 | 4.8-7.4V |
| 空载转速 | 60°/0.16s @ 6V |
| 额定扭矩 | 21 kg·cm @ 6V |
| 控制脉宽 | 500-2500μs |
| 中立位置 | 1500μs (90°) |
| 转向范围 | 0-180° (270° 改装) |
| 精度 | ±1° |
| 回程差 | <5° |
| 齿轮 | 金属齿轮 |
| 壳体材质 | 铁壳 |
| 重量 | 60g |
| 尺寸 | 40.7×20.2×36.2mm |

**12个舵机总参数**:
- 总转矩: 21×12 = 252 kg·cm
- 总功耗: 12×1A (空载) ~ 12×3A (堵转)
- 总重量: 720g

---

## 装配关键点

1. **髋关节**
   - U型支架的40mm侧向偏移是关键，影响腿的工作范围
   - 双轴承支撑确保刚性和精度
   - 螺丝要拧紧，但不要过度

2. **肩膝关节**
   - 两个Y轴关节形成串联机制
   - 肩关节转角×膝关节转角的复合运动产生抬腿效果
   - 膝关节的反向范围限制(-149°~-5.7°)模拟真实膝盖的单向弯曲

3. **腿长配置**
   - 上腿100mm + 下腿100mm = 200mm总长
   - 脚垫直径15mm
   - 站立高度约150mm(机身36mm + 腿长200mm - 地面间隙)

4. **重心平衡**
   - 肩膝舵机靠下方，利于重心后移
   - 电池位置可前后移动调整俯仰稳定性
   - 目标重心: 机身板中心正上方30mm处

---

## 参考文档

- **URDF模型**: `/urdf/dino_quadruped.urdf`
- **CAD图纸**: `/cad/` (待完善)
- **设计参数**: `/docs/机械结构设计.md`
- **仿真环境**: Gazebo / PyBullet

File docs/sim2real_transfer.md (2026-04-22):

# 恐龙四足机器人 - Sim2Real Transfer 指南

## 什么是 Sim2Real Transfer

Sim2Real Transfer（仿真到真实迁移）是指将 PyBullet 仿真中训练/调好的控制策略，
部署到真实物理机器人上并保持正常工作的过程。

核心挑战：**Reality Gap（现实差距）**——仿真中完美行走的策略直接部署到实机往往失败。

---

## Reality Gap 的来源

| 仿真假设 | 真实情况 | 影响 |
|---|---|---|
| 舵机瞬间到达目标角度 | DS3218 响应延迟 ~0.15s/60° | 动作滞后，步态失调 |
| 关节无间隙 | 3D 打印件装配间隙、齿轮回差 | 位置精度下降 |
| 地面完美平坦 | 地面不平、摩擦系数不均 | 滑动、绊倒 |
| 传感器无噪声 | MPU6050 有漂移和噪声 | 状态估计不准 |
| 质量/惯量精确 | 实际重量分布与 URDF 有偏差 | 重心偏移、动力学不匹配 |
| 控制频率稳定 50Hz | 树莓派 I2C 通信有抖动 | 控制周期不均匀 |
| 碰撞为刚体 | 脚垫有弹性、关节有柔性 | 接触力学不同 |

---

## 三层解决方案

### 第一层：Domain Randomization（仿真端）

在 PyBullet 训练时故意加入随机扰动，让策略"见过各种糟糕情况"，
到实机上就不容易崩。

#### 需要随机化的参数

```python
# 在 rl/dino_env.py 的 reset() 中加入随机化
randomization_ranges = {
    # 动力学参数
    "body_mass":       (1.2, 1.8),    # kg, 标称 1.5 ±20%
    "friction":        (0.4, 1.0),    # 地面摩擦系数
    "joint_damping":   (0.01, 0.1),   # 关节阻尼
    "joint_friction":  (0.0, 0.05),   # 关节摩擦

    # 执行器特性
    "action_delay":    (1, 3),        # 控制步延迟 (模拟舵机响应)
    "action_noise":    (0.0, 0.02),   # 动作噪声 (rad)
    "torque_scale":    (0.8, 1.2),    # 扭矩缩放

    # 传感器噪声
    "imu_accel_noise": (0.0, 0.5),    # m/s² 加速度噪声
    "imu_gyro_noise":  (0.0, 0.05),   # rad/s 角速度噪声
    "imu_gyro_drift":  (0.0, 0.01),   # rad/s 陀螺仪漂移

    # 环境
    "ground_slope":    (-5, 5),       # 度, 地面倾斜
    "push_force":      (0, 3),        # N, 随机侧向推力
}
```

#### 随机化策略

- **均匀随机化**：每次 reset() 时从范围内均匀采样
- **渐进式**：训练前期不加或少加随机化，后期逐渐增大范围
- **相关性**：某些参数可以关联随机化（如质量增大时惯量也增大）

### 第二层：System Identification（实机端）

用实际硬件数据修正仿真模型，缩小仿真与现实的差距。

#### 2.1 质量/惯量标定

```
操作步骤：
1. 电子秤称量每个零件实际重量
2. 更新 urdf/dino.urdf 中的 mass 和 inertia
3. 安装完成后称量整机重量
4. 用吊线法测量实际重心位置

需要记录：
  部件              设计值(g)   实测值(g)
  ────────────────────────────────────
  机身框架          120         ?
  树莓派 3B          45         ?
  PCA9685           15         ?
  电池              280         ?
  单个 DS3218        60         ?
  ...
  总重              1500         ?
```

#### 2.2 舵机响应曲线

```python
# 在实机上测量舵机实际响应特性
# 发送阶跃信号，记录到达时间

# 测量项：
# - 空载响应时间：0° → 60° 需要多少 ms
# - 负载响应时间：带负载（腿重量）的响应时间
# - 回差测量：正转到 90° 再反转回来，偏差多少度
# - 实际角度精度：命令 45° 实际到达多少度

# 用这些数据更新仿真中的关节参数：
# - maxVelocity
# - jointDamping
# - lateralFriction
```

#### 2.3 IMU 噪声特性

```bash
# 静止状态采集 60 秒数据
python3 hardware/04_imu_test.py > imu_static_60s.csv

# 分析：
# - 加速度计零偏 (bias)
# - 加速度计噪声方差 (noise)
# - 陀螺仪零偏和漂移率
# - Allan 方差（可选，更精确）
```

#### 2.4 地面摩擦测量

```
简易方法：
1. 将机器人脚垫放在目标地面上
2. 逐渐倾斜，记录开始滑动的角度 θ
3. 摩擦系数 μ = tan(θ)
4. 更新 PyBullet 中的 lateralFriction 参数
```

### 第三层：渐进式部署（实机端）

不直接跑完整策略，分步验证，逐步提高复杂度。

```
Step 1: 站立
  └─ 验证 IK 角度映射正确
  └─ 脚本: hardware/05_stand_test.py
  └─ 通过标准: 四脚着地、机身水平、高度 ~150mm

Step 2: 单腿抬放
  └─ 固定三条腿站立，一条腿做抬起/放下动作
  └─ 验证单腿轨迹跟踪精度
  └─ 确认舵机响应速度够用

Step 3: 慢速 Trot
  └─ 脚本: hardware/06_trot_test.py --slow
  └─ 步幅减半、周期加倍
  └─ 确认基础步态可行

Step 4: 正常速度 Trot（固定步态）
  └─ 脚本: hardware/06_trot_test.py
  └─ 确认动态稳定性

Step 5: 部署 RL 策略（v7 PPO 模型）
  └─ 用 RL 模型输出替代固定步态生成器
  └─ 树莓派上用 ONNX Runtime 推理
  └─ 50Hz 控制循环: IMU 读取 → 模型推理 → 舵机输出
```

---

## 控制频率适配

### 仿真 vs 实机的频率差距

RL v7 策略的仿真控制频率：
```
PyBullet 物理步进: 240Hz  (dt = 1/240 = 4.17ms)
action_repeat:     2
RL 控制频率:       240 / 2 = 120Hz
RL 控制周期:       8.33ms
```

实机硬件能支持的控制频率取决于信号链路中最慢的环节：

### Phase 1 硬件 (PCA9685 + DS3218) 的频率瓶颈

```
120Hz 控制周期 = 8.33ms，信号链路耗时:

  环节              硬件              耗时        能否满足
  ──────────────────────────────────────────────────────
  IMU 读取          MPU6050 I2C       ~1.5ms      ✅
  RL 推理           Pi 3B CPU (ONNX)  ~5-8ms      ⚠️ 勉强
  舵机指令下发       PCA9685 I2C       ~12ms       ❌ 超时!
  ──────────────────────────────────────────────────────
  合计                                ~19-22ms
  最大可达频率                         ~50Hz

PCA9685 更新 12 个通道的耗时计算:
  单通道: 写 4 字节寄存器, I2C 开销 + Python 驱动 ≈ ~1.0ms
  12 通道 (串行): 12 × 1.0ms = ~12ms
  加上 IMU 共享 I2C 总线: 12ms + 1.5ms = 13.5ms ❌

结论: PCA9685 是 120Hz 的硬性瓶颈，软件优化无法解决。
```

### Phase 2 硬件 (STS3215 + Pi 4B) 的频率能力

```
120Hz 控制周期 = 8.33ms，信号链路耗时:

  环节              硬件              耗时        能否满足
  ──────────────────────────────────────────────────────
  IMU 读取          MPU6050 I2C       ~0.5ms      ✅ (总线空闲)
  RL 推理           Pi 4B CPU (ONNX)  ~2-3ms      ✅
  舵机指令下发       STS3215 SyncWrite ~1.5ms      ✅
  反馈读取 (可选)   STS3215 SyncRead  ~2.0ms      ✅
  ──────────────────────────────────────────────────────
  合计                                ~4-7ms      ✅ 余量充足
  最大可达频率                         ~200Hz+

STS3215 SyncWrite 耗时计算:
  包头(2B) + 广播ID(1B) + 长度(1B) + 指令(1B) + 起始地址(1B)
  + 12 × [ID(1B) + posL(1B) + posH(1B)] = ~42 字节
  42 字节 × 10bit ÷ 1Mbps ≈ 0.42ms
  加上协议开销 ≈ ~1.0-1.5ms ✅
```

### 降频适配方案 (不升级硬件时)

如果暂不升级硬件，可以在实机上降低控制频率：

```python
# 方案 A: 降到 50Hz（PCA9685 安全范围）
# 需要重新训练 RL 策略
# dino_env.py 中修改:
self.action_repeat = 5   # 240/5 = 48Hz ≈ 50Hz

# 影响:
# - 控制延迟从 8.33ms → 20.8ms
# - 步态平滑度下降
# - 可能需要调整 reward 函数中的平滑项权重
# - 对 sim2real gap 的容忍度降低

# 方案 B: 降到 60Hz（PCA9685 极限）
self.action_repeat = 4   # 240/4 = 60Hz

# 需要优化 PCA9685 写入:
# - 使用批量写入模式 (连续寄存器地址)
# - 预计从 ~12ms 压缩到 ~8ms
# - 加上 IMU ~1.5ms 仍然紧张
# - 不推荐，频率不稳定

# 方案 C: 混合方案（推荐的过渡策略）
# Phase 1 用 50Hz (action_repeat=5) 做基础验证
# 确认算法可行后，升级到 Phase 2 硬件跑 120Hz
```

### 不同频率下的性能预估

| 控制频率 | action_repeat | 硬件要求 | 步态质量 | sim2real 难度 |
|---|---|---|---|---|
| 120Hz | 2 | STS3215 + Pi 4B | 最佳 (仿真同款) | 最低 |
| 60Hz | 4 | PCA9685 极限 | 良好 | 中等 |
| 50Hz | 5 | PCA9685 安全 | 可用 | 较高 (需重训练) |
| 30Hz | 8 | PCA9685 轻松 | 勉强 | 高 (明显延迟) |

---

## RL 策略实机部署架构

### Phase 1: PCA9685 方案 (50Hz)

```
┌──────────────────────────────────────────────────┐
│                 树莓派 3B                         │
│                                                  │
│   ┌────────────┐    ┌──────────────────────┐     │
│   │ MPU6050    │    │   RL Policy (ONNX)   │     │
│   │ IMU 读取   │──►│                      │     │
│   │ (I2C 共享) │    │  观测 (41维):         │     │
│   └────────────┘    │   - 关节角度 (12)     │     │
│                     │   - 关节角速度 (12)    │     │
│   ┌────────────┐    │   - 机身姿态 (6)     │     │
│   │ PCA9685    │◄──│   - 步态相位 (2)     │     │
│   │ 舵机控制   │    │   - 其他 (9)         │     │
│   │ (I2C 共享) │    │                      │     │
│   └────────────┘    │  输出:               │     │
│                     │   - 关节角度增量 (12) │     │
│                     └──────────────────────┘     │
│                                                  │
│   控制循环 (20ms / 50Hz):                        │
│   1. 读取 IMU (加速度+角速度)          ~1.5ms    │
│   2. 组装观测向量                      ~0.1ms    │
│   3. ONNX 推理                         ~5-8ms    │
│   4. 后处理 + 安全限幅                  ~0.1ms    │
│   5. 发送 12 路舵机指令 (I2C)          ~10ms     │
│   ─────────────────────────────                  │
│   总计:                                ~17ms     │
│   余量:                                ~3ms      │
│                                                  │
│   ⚠️ 无位置反馈，开环控制                         │
│   ⚠️ I2C 总线被 PCA9685+MPU6050 共享，互相争抢    │
└──────────────────────────────────────────────────┘
```

### Phase 2: STS3215 方案 (120Hz) — 升级后

```
┌──────────────────────────────────────────────────┐
│                 树莓派 4B                         │
│                                                  │
│   ┌────────────┐    ┌──────────────────────┐     │
│   │ MPU6050    │    │   RL Policy (ONNX)   │     │
│   │ IMU 读取   │──►│                      │     │
│   │ (I2C 独占) │    │  观测 (41维):         │     │
│   └────────────┘    │   - 关节角度 (12)     │     │
│                     │   - 关节角速度 (12)    │     │
│   ┌────────────┐    │   - 机身姿态 (6)     │     │
│   │ STS3215    │◄──│   - 步态相位 (2)     │     │
│   │ 总线舵机   │──►│   - 其他 (9)         │     │
│   │ (UART 独立)│    │                      │     │
│   └────────────┘    │  输出:               │     │
│    ↑↓ 双向通信       │   - 关节角度增量 (12) │     │
│    位置/负载/温度     └──────────────────────┘     │
│                                                  │
│   控制循环 (8.33ms / 120Hz):                     │
│   1. 读取 IMU (加速度+角速度)          ~0.5ms    │
│   2. 读取 12 路关节位置 (SyncRead)     ~2.0ms    │
│   3. 组装观测向量                      ~0.1ms    │
│   4. ONNX 推理                         ~2-3ms    │
│   5. 后处理 + 安全限幅                  ~0.1ms    │
│   6. 发送 12 路舵机指令 (SyncWrite)    ~1.5ms    │
│   ─────────────────────────────                  │
│   总计:                                ~6.2ms    │
│   余量:                                ~2.1ms    │
│                                                  │
│   ✅ 位置反馈闭环                                 │
│   ✅ I2C 和 UART 独立总线，互不干扰              │
│   ✅ 温度/负载实时监控                            │
└──────────────────────────────────────────────────┘
```

### 模型导出

```python
# 训练完成后，将 PPO 模型导出为 ONNX
import torch

model = PPO.load("rl/checkpoints/v7_best.zip")
policy = model.policy

dummy_obs = torch.randn(1, obs_dim)
torch.onnx.export(
    policy,
    dummy_obs,
    "rl/checkpoints/v7_policy.onnx",
    input_names=["observation"],
    output_names=["action"],
    opset_version=11,
)
```

### 实机推理

```python
# ===== Phase 1: 50Hz (Pi 3B + PCA9685) =====
import onnxruntime as ort

session = ort.InferenceSession("v7_50hz_policy.onnx")

while running:
    obs = get_observation()  # IMU only (无位置反馈)
    action = session.run(None, {"observation": obs})[0]
    action = np.clip(action, -action_limit, action_limit)
    send_to_servos_pwm(action)      # PCA9685 I2C
    time.sleep(0.02)                 # 50Hz

# ===== Phase 2: 120Hz (Pi 4B + STS3215) =====
import onnxruntime as ort
from SCServo import SMS_STS

session = ort.InferenceSession("v7_policy.onnx")
sts = SMS_STS()
sts.open_port("/dev/ttyUSB0", 1000000)

while running:
    t0 = time.time()

    # 读传感器 (I2C 和 UART 并行无冲突)
    imu_data = read_imu()                          # ~0.5ms
    joint_pos = sts.SyncReadPos([1..12])           # ~2.0ms

    # 推理
    obs = build_observation(imu_data, joint_pos)   # ~0.1ms
    action = session.run(None, {"observation": obs})[0]  # ~2.5ms
    action = np.clip(action, -action_limit, action_limit)

    # 执行 + 安全监控
    positions = action_to_positions(action)
    sts.SyncWritePosEx(ids, positions, speeds, accs)  # ~1.5ms

    # 安全检查 (每 10 帧读一次温度，避免占用带宽)
    if frame_count % 10 == 0:
        temps = [sts.ReadTemperature(i) for i in range(1,13)]
        if max(temps) > 60:
            print("过热保护!")
            break

    # 精确定时
    elapsed = time.time() - t0                     # 合计 ~6ms
    time.sleep(max(0, 0.00833 - elapsed))          # 补齐到 8.33ms
```

---

## 评估指标

部署后需要对比仿真和实机的性能差异：

| 指标 | 仿真值 (v7) | 实机目标 (50Hz) | 实机目标 (120Hz) | 测量方法 |
|---|---|---|---|---|
| 站立稳定性 | CoM 偏移 <2mm | <8mm | <5mm | IMU 积分 |
| 行走速度 | ~0.15 m/s | >0.08 m/s | >0.12 m/s | 秒表 + 距离 |
| Roll/Pitch 幅度 | <5° | <15° | <10° | IMU 数据 |
| 续航时间 | N/A | >60 min | >45 min | 实测 |
| 抗扰能力 | 侧推 3N | 侧推 1N | 侧推 2N | 手动推测 |
| 关节跟踪误差 | 0° (理想) | 未知 (无反馈) | <1° | STS3215 反馈 |
| 控制频率稳定性 | 120Hz 恒定 | 45-55Hz 波动 | 115-125Hz 稳定 | 实测 |

---

## 参考路线图

```
当前位置
    │
    ▼
┌─────────────────────────┐
│ v7 平滑行走优化 (仿真)    │  ← 已完成
│ - PPO 训练收敛            │     action_repeat=2, 120Hz
│ - 仿真中稳定 trot         │
└────────────┬────────────┘
             │
             ▼
┌─────────────────────────────────────────────────────────┐
│ Phase 1 实机验证 (50Hz, PCA9685 + DS3218 + Pi 3B)       │
│                                                         │
│ - 重训练 50Hz 策略 (action_repeat=5) 或用固定步态         │
│ - 硬件验证: 站立 → 慢走 → 固定步态行走                    │
│ - System ID: 称重、测摩擦、测舵机响应                     │
│ - 基础 Domain Randomization                             │
│ - 验证整体流程可行性                                     │
│                                                         │
│ 通过标准: 固定步态稳定走 10 秒                            │
└────────────┬────────────────────────────────────────────┘
             │
             ▼
┌─────────────────────────────────────────────────────────┐
│ Phase 2 硬件升级 (120Hz, STS3215 + Pi 4B)               │
│                                                         │
│ - 替换舵机 + 主控 (详见 硬件升级变更清单.md)              │
│ - 位置反馈闭环校准                                       │
│ - 精确 System ID (实测舵机响应曲线)                       │
│ - 直接部署 v7 120Hz RL 策略                              │
│                                                         │
│ 通过标准: RL 策略实机走 5 秒不倒                          │
└────────────┬────────────────────────────────────────────┘
             │
             ▼
┌─────────────────────────────────────────────────────────┐
│ 工控机联调                                               │
│                                                         │
│ - 网线直连工控机/笔记本                                   │
│ - ROS 多机通信: rviz 可视化 + rosbag 录包                │
│ - 仿真-实机轨迹对比分析                                  │
│ - 迭代优化 Domain Randomization 参数                     │
└─────────────────────────────────────────────────────────┘
```

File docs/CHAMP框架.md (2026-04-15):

# CHAMP 框架知识

CHAMP = **C**onfiguration-**H**andled **A**utonomous **M**otion **P**lanner

一个专为 SpotMicro 等小型四足机器人设计的开源 ROS 运动控制框架。
本项目基于 CHAMP 的架构思路，但用 RL 替换了核心步态规划模块。

---

## 1. CHAMP 是什么

CHAMP 是一个完整的四足机器人 ROS 软件栈，提供：
- 步态生成 (Gait Generator)
- 逆运动学求解 (IK Solver)
- 机身姿态控制 (Body Pose Controller)
- 里程计估计 (Odometry)
- 自主导航集成 (Navigation via move_base)

```
传感器输入 (IMU / LiDAR / 里程计)
         ↓
┌──────────────────────────────────────┐
│             CHAMP 框架                │
│                                      │
│  ┌──────────────┐  ┌──────────────┐  │
│  │  步态生成器    │  │  逆运动学     │  │
│  │  Gait        │→│  IK Solver   │  │
│  │  Generator   │  │  (解析解)     │  │
│  └──────────────┘  └──────┬───────┘  │
│                           ↓          │
│  ┌──────────────┐  ┌──────────────┐  │
│  │  姿态控制     │  │  关节控制     │  │
│  │  Body Pose   │  │  Joint       │  │
│  │  Controller  │  │  Publisher    │  │
│  └──────────────┘  └──────────────┘  │
└──────────────────────────────────────┘
         ↓
  /joint_states → 舵机/电机驱动
```

---

## 2. 核心组件详解

### 2.1 步态生成器 (Gait Generator)

生成四条腿的足端轨迹，支持多种步态：

| 步态 | 相位 | 特点 | 速度 |
|---|---|---|---|
| **Walk** | 0-25-50-75 | 始终三脚着地，最稳定 | 慢 |
| **Trot** | 0-50-50-0 | 对角腿同步，效率最高 | 中 |
| **Pace** | 0-50-0-50 | 同侧腿同步 | 中 |
| **Gallop** | 0-10-50-60 | 类似奔跑 | 快 |

步态生成器的核心参数：
```
step_length:  步幅 (前后方向移动距离)
step_height:  抬腿高度 (足端离地最高点)
period:       一个完整步态周期的时间
phase_offset: 各腿的相位差 (决定步态类型)
```

**Trot 步态的数学描述：**

```
对于每条腿，足端在一个周期内的轨迹:

摆动相 (swing, 腿在空中):
  x(t) = step_length * (0.5 - t/T_swing)          // 前后移动
  z(t) = step_height * sin(π * t / T_swing)        // 抬起-落下

支撑相 (stance, 腿在地面):
  x(t) = step_length * (t/T_stance - 0.5)          // 向后推
  z(t) = 0                                         // 贴地

Trot 相位:
  FL 和 RR: phase = 0    (同时摆动)
  FR 和 RL: phase = 0.5  (另一对角同时摆动)
```

### 2.2 逆运动学 (IK Solver)

将足端坐标 (x, y, z) 转换为关节角度 (hip, shoulder, knee)。

CHAMP 使用 **3-DOF 解析解**（不是数值迭代），计算速度极快：

```
输入: 足端目标位置 (x, y, z)，相对于髋关节
输出: (θ_hip, θ_shoulder, θ_knee)

θ_hip = atan2(y, z)                         // 髋关节: 左右摆动

L = sqrt(x² + (sqrt(y² + z²) - L_hip)²)    // 足端到肩关节的距离
φ = atan2(x, sqrt(y² + z²) - L_hip)         // 倾斜角

// 余弦定理求肩关节和膝关节角度
θ_knee = acos((L_upper² + L_lower² - L²) / (2 * L_upper * L_lower))
θ_shoulder = φ + acos((L_upper² + L² - L_lower²) / (2 * L_upper * L))
```

其中：
- `L_hip`: 髋关节到肩关节的偏移距离
- `L_upper`: 大腿长度 (本项目 100mm)
- `L_lower`: 小腿长度 (本项目 100mm)

### 2.3 机身姿态控制 (Body Pose Controller)

允许在行走的同时调整机身姿态：

```
6 维姿态控制:
  - x: 前后平移
  - y: 左右平移
  - z: 上下调整 (站立高度)
  - roll:  翻滚 (左右倾斜)
  - pitch: 俯仰 (前后倾斜)
  - yaw:   偏航 (左右转向)
```

实现方式：对足端坐标做逆变换
```
foot_adjusted = R_body_inverse × (foot_original - body_offset)
```

### 2.4 里程计 (Odometry)

通过足端运动学估计机器人位移：
- 支撑相的腿"推着地面走"
- 通过计算支撑腿的运动来估计机身移动
- 结合 IMU 数据修正漂移

### 2.5 导航 (Navigation)

集成 ROS 标准导航栈：
```
move_base → cmd_vel → CHAMP → joint_states → 舵机
                ↑
            costmap (LiDAR 建图)
```

---

## 3. CHAMP 的 ROS Topic 接口

### 订阅 (输入)

| Topic | 类型 | 说明 |
|---|---|---|
| `/cmd_vel` | geometry_msgs/Twist | 速度指令 (vx, vy, wz) |
| `/body_pose` | geometry_msgs/Pose | 机身姿态指令 |
| `/imu/data` | sensor_msgs/Imu | IMU 数据 |

### 发布 (输出)

| Topic | 类型 | 频率 | 说明 |
|---|---|---|---|
| `/joint_states` | sensor_msgs/JointState | 50-100Hz | 12 个关节目标角度 |
| `/odom` | nav_msgs/Odometry | 50Hz | 里程计 |
| `/foot_contacts` | champ_msgs/ContactsStamped | 50Hz | 足端触地状态 |
| `/cmd_pose` | geometry_msgs/PoseArray | 50Hz | 四个足端的目标位置 |

---

## 4. CHAMP 的配置系统

CHAMP 的核心特点是 **配置驱动**——通过 YAML 文件定义机器人参数，无需改代码：

```yaml
# champ_config.yaml
robot:
  base:
    hip_length: 0.04     # 髋关节偏移
    upper_leg: 0.10      # 大腿长度
    lower_leg: 0.10      # 小腿长度
    body_length: 0.20    # 机身长度
    body_width: 0.11     # 机身宽度

  gait:
    max_linear_velocity_x: 0.5
    max_linear_velocity_y: 0.25
    max_angular_velocity_z: 1.0
    stance_duration: 0.25
    swing_height: 0.03
    nominal_height: 0.15

  joints:
    # 每个关节的名称、方向、偏移
    front_left:
      hip: {offset: 0, direction: 1}
      upper_leg: {offset: 0, direction: 1}
      lower_leg: {offset: 0, direction: 1}
    # ... 其他腿
```

---

## 5. 本项目与 CHAMP 的对应关系

| CHAMP 组件 | 本项目对应实现 | 文件位置 |
|---|---|---|
| Gait Generator | `TrotGait` 类 | `scripts/sim_standalone.py` |
| IK Solver | `leg_ik()` 函数 | `scripts/sim_standalone.py` |
| Body Pose Controller | 仿真中的 body_height 参数 | `scripts/sim_standalone.py` |
| Joint Publisher | `hardware/05_stand_test.py`, `06_trot_test.py` | `hardware/` |
| Navigation | 未实现 | - |
| Odometry | 未实现 | - |
| **RL 策略** (CHAMP 没有) | PPO v7 模型 | `rl/train_ppo.py` |

### 关键区别

```
CHAMP (传统方法):
  cmd_vel → 步态生成器 (固定规则) → IK → 关节角度
  - 优点: 可预测、可调试、参数明确
  - 缺点: 适应性差、难以处理复杂地形

本项目 (RL 方法):
  观测 (IMU + 关节状态) → PPO 神经网络 → 关节角度
  - 优点: 自适应、可泛化到未见过的地形
  - 缺点: 黑盒、难调试、需要大量仿真训练

混合方案 (推荐):
  1. 用 CHAMP 风格的固定步态做基础验证 (Phase 1)
  2. 用 RL 策略替换步态生成器 (Phase 2)
  3. 保留 IK + 姿态控制作为 fallback
```

---

## 6. CHAMP 的技术栈

```
┌─────────────────────────────────────────────┐
│                 应用层                       │
│  move_base / SLAM / 路径规划                  │
├─────────────────────────────────────────────┤
│                 CHAMP 层                     │
│  步态生成 / IK / 姿态控制 / 里程计             │
├─────────────────────────────────────────────┤
│                 ROS 层                       │
│  topic 通信 / tf 坐标变换 / urdf 模型          │
├─────────────────────────────────────────────┤
│                 硬件抽象层 (HAL)              │
│  ros_control / 舵机驱动 / IMU 驱动            │
├─────────────────────────────────────────────┤
│                 硬件层                       │
│  舵机 / IMU / LiDAR / 电池                   │
└─────────────────────────────────────────────┘
```

### 本项目的简化栈

```
┌─────────────────────────────────────────────┐
│                 控制层                       │
│  TrotGait (固定步态) 或 PPO (RL 策略)          │
├─────────────────────────────────────────────┤
│                 运动学层                     │
│  leg_ik() 逆运动学                           │
├─────────────────────────────────────────────┤
│                 驱动层                       │
│  PCA9685 + adafruit-servokit                │
├─────────────────────────────────────────────┤
│                 硬件层                       │
│  DS3218 舵机 / MPU6050 / 树莓派 3B           │
└─────────────────────────────────────────────┘
```

---

## 7. 如何从本项目迁移到完整 CHAMP

如果后续想接入 ROS 生态（SLAM、导航等），可以：

### Step 1: 安装 CHAMP

```bash
# ROS Noetic
cd ~/catkin_ws/src
git clone --recursive https://github.com/chvmp/champ.git
git clone https://github.com/chvmp/champ_teleop.git
cd ..
catkin_make
```

### Step 2: 配置机器人参数

```bash
rosrun champ_setup_assistant setup_assistant.py
# GUI 工具，输入 URDF 文件和关节参数
# 自动生成 champ_config.yaml
```

### Step 3: 编写硬件接口

需要一个 ROS 节点将 `/joint_states` 转发到 PCA9685：

```python
#!/usr/bin/env python3
"""将 CHAMP 输出的关节角度发送到 PCA9685 舵机。"""

import rospy
from sensor_msgs.msg import JointState
from hardware.servo_config import CHANNEL_MAP, rad_to_us, us_to_pca

def joint_callback(msg):
    for name, position in zip(msg.name, msg.position):
        if name in CHANNEL_MAP:
            ch = CHANNEL_MAP[name]
            pulse_us = rad_to_us(position, name)
            pca.channels[ch].duty_cycle = us_to_pca(pulse_us)

rospy.init_node('dino_hardware_interface')
rospy.Subscriber('/joint_states', JointState, joint_callback)
rospy.spin()
```

### Step 4: 启动

```bash
# 终端 1: CHAMP 核心
roslaunch dino_config bringup.launch

# 终端 2: 键盘遥控
roslaunch champ_teleop teleop.launch

# 终端 3 (工控机): 可视化
roslaunch dino_config rviz.launch
```

---

## 8. CHAMP 生态中的相关项目

| 项目 | 说明 | 链接 |
|---|---|---|
| **champ** | 核心运动控制框架 | github.com/chvmp/champ |
| **champ_teleop** | 键盘/手柄遥控 | github.com/chvmp/champ_teleop |
| **champ_setup_assistant** | GUI 配置工具 | 内含于 champ |
| **SpotMicroAI** | SpotMicro 社区项目 | github.com/mike4192/spotMicro |
| **spot_mini_mini** | 基于 RL 的 SpotMicro | github.com/moribots/spot_mini_mini |
| **OpenQuadruped** | 开源四足平台 | github.com/adham-elarabawy/open-quadruped |

---

## 9. 总结

CHAMP 是"四足机器人的 ROS 运动控制中间件"。本项目：
- **借鉴了 CHAMP 的架构**（步态生成 + IK + 关节控制的分层设计）
- **没有直接使用 CHAMP 代码**（用 Python 重新实现，更轻量）
- **用 RL (PPO) 扩展了 CHAMP 没有的能力**（自适应步态）
- **后续可以桥接回 CHAMP 生态**（接入 ROS 导航/SLAM）

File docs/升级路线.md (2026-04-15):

# 恐龙四足机器人 - 硬件升级路线

从当前 DIY 方案逐步升级到接近商用产品水平的渐进路线。
核心原则：**先跑通流程，再逐步升级**。

---

## 总览

```
Phase 1 (当前)          Phase 2              Phase 3              Phase 4
DS3218 模拟舵机         总线舵机              铝合金结构            FOC 关节电机
3D 打印 PLA            3D 打印              CNC 铝合金            CNC 铝合金
PCA9685 PWM            TTL 串行总线          TTL 串行总线          CAN 总线
无位置反馈              有位置反馈            有位置反馈            力矩+位置反馈
~500 元                ~1500 元             ~3000 元             ~8000 元

│  验证算法可行性        │  提升控制精度        │  提升结构强度        │  接近商用水平
│  sim2real 初体验      │  真正的闭环控制      │  长期稳定运行        │  力控/柔顺控制
```

---

## Phase 1: 当前方案（验证阶段）

### 硬件配置

| 组件 | 型号 | 数量 | 单价 | 小计 |
|---|---|---|---|---|
| 舵机 | DS3218 (21kg·cm, 270°) | 12 | ~25 元 | 300 元 |
| 驱动板 | PCA9685 | 1 | ~15 元 | 15 元 |
| IMU | MPU6050 (GY-521) | 1 | ~8 元 | 8 元 |
| 主控 | 树莓派 3B | 1 | ~200 元 | 200 元 |
| 降压模块 | LM2596 | 2 | ~5 元 | 10 元 |
| 电池 | 2S 7.4V 5000mAh | 1 | ~80 元 | 80 元 |
| 结构件 | 3D 打印 PLA | 1 套 | ~50 元 | 50 元 |
| **合计** | | | | **~660 元** |

### 目标

- [x] PyBullet 仿真调通
- [ ] 实机站立
- [ ] 实机行走（固定步态）
- [ ] RL 策略部署

### 瓶颈

- 舵机无反馈，不知道实际角度 → sim2real gap 大
- PWM 控制精度 ±2°，死区明显
- 3D 打印件刚度不足，关节有间隙
- 控制频率受 I2C 限制，~50Hz

---

## Phase 2: 总线舵机升级（精度提升）

### 升级内容

| 替换 | 旧 | 新 | 变化 |
|---|----|----|---|
| 舵机 | DS3218 (PWM) | Feetech STS3215 (TTL 总线) | +位置反馈, +精度 |
| 驱动 | PCA9685 | UART 串口直连 | 去掉 I2C 瓶颈 |
| 通信 | I2C → PWM (单向) | UART → TTL (双向) | 可读角度/电流/温度 |

### 关键型号选择

**推荐: Feetech STS3215**

| 参数 | DS3218 (当前) | STS3215 (升级) |
|---|---|---|
| 扭矩 | 21 kg·cm | 15 kg·cm |
| 角度范围 | 270° | 360° (连续) |
| 通信 | PWM | TTL 串行总线 |
| 位置反馈 | ❌ | ✅ 12-bit 磁编码器 (0.088°) |
| 速度反馈 | ❌ | ✅ |
| 电流反馈 | ❌ | ✅ (间接力矩) |
| 温度反馈 | ❌ | ✅ |
| 通信速率 | 50Hz (PCA9685) | 1Mbps (可达 100Hz+) |
| ID 设置 | 靠通道号 | 软件设 ID, 菊花链 |
| 单价 | ~25 元 | ~60 元 |

**备选: Dynamixel XL330-M288-T**
- Robotis 出品，生态最好，但单价 ~200 元，12 个就 2400 元

### 软件改动

```python
# Phase 1: PCA9685 PWM (单向)
kit.servo[channel].angle = target_angle  # 发了就不管了

# Phase 2: STS3215 TTL 总线 (双向)
sts.write_pos(servo_id, target_pos)      # 发指令
actual_pos = sts.read_pos(servo_id)       # 读实际位置
error = target_pos - actual_pos           # 可以做闭环!
```

### 预算增量

- 12 × STS3215: ~720 元
- TTL 转接板: ~30 元
- 减去 PCA9685 + DS3218: -315 元
- **净增: ~435 元**（总计 ~1100 元）

### 收益

- 闭环控制：知道舵机实际位置，大幅缩小 sim2real gap
- System Identification：可以测量真实的舵机响应曲线
- 过载保护：不再烧舵机
- 更高控制频率：100Hz+

---

## Phase 3: 铝合金结构（刚度提升）

### 升级内容

| 替换 | 旧 | 新 |
|---|----|----|
| 机身底板/顶板 | 3D 打印 PLA | 2mm 铝合金板 (CNC 或激光切割) |
| 腿部连杆 | 3D 打印 PLA | 2mm 铝合金 + 轴承 |
| 关节支架 | 3D 打印 | 铝合金折弯件 |
| 紧固件 | M3 螺丝 | M3 不锈钢 + 螺纹胶 |

### 加工方式

| 方案 | 精度 | 单价 | 适合 |
|---|---|---|---|
| 淘宝激光切割 | ±0.1mm | ~200 元/套 | 平板件 (底板/连杆) |
| 淘宝 CNC 加工 | ±0.05mm | ~800 元/套 | 复杂 3D 件 (支架) |
| 自行折弯 | ±0.5mm | ~100 元/套 | 简单 L 型支架 |

### 预算增量

- 铝合金结构件: ~500-1500 元（取决于加工方式）
- **总计: ~1600-2600 元**

### 收益

- 消除 3D 打印件的弹性形变
- 关节间隙大幅减小
- 可长期反复运动，不会断裂
- 整体重量可能更轻（铝比实心 PLA 轻）

---

## Phase 4: FOC 关节电机（终极方案）

### 升级内容

将总线舵机替换为一体化 FOC 关节电机模块：

| 型号选择 | 扭矩 | 通信 | 反馈 | 单价 |
|---|---|---|---|---|
| CubeMars AK60-6 | 6 Nm | CAN | 位置+速度+力矩 | ~500 元 |
| T-Motor AK10-9 | 9 Nm | CAN | 位置+速度+力矩 | ~800 元 |
| 海力禾 MF 系列 | 可选 | CAN | 全状态 | ~300-600 元 |

### 核心变化

```
Phase 1-3: 位置控制
  目标角度 → 舵机转到位 → 完成

Phase 4: 力矩控制 (全新能力)
  目标力矩 → 关节输出力 → 可做柔顺控制
  - 碰到障碍物时"软"下来，不硬刚
  - 可以做 impedance control（阻抗控制）
  - 摔倒时自动卸力，保护结构
```

### 预算增量

- 12 × FOC 电机: ~3600-9600 元
- CAN 总线板: ~100 元
- 更大电池 (电流需求增加): ~200 元
- **总计: ~5000-12000 元**

### 收益

- 真正的力矩控制，接近 MIT Mini Cheetah 的控制架构
- 1kHz 控制频率
- sim2real gap 极小
- 可以跑最前沿的 RL 策略 (如 NVIDIA Isaac Lab 训练的)

---

## 升级决策树

```
Q1: 仿真中的算法已经跑通了吗？
  ├── 否 → 留在 Phase 1，先跑通仿真
  └── 是 → Q2

Q2: 实机能站稳、慢走了吗？
  ├── 否 → 留在 Phase 1，用 05_stand_test.py 校准
  └── 是 → Q3

Q3: sim2real gap 导致 RL 策略无法部署？
  ├── 主要是角度不准 → 升级 Phase 2 (总线舵机)
  ├── 主要是结构变形 → 升级 Phase 3 (铝合金)
  └── 需要力矩控制 → 升级 Phase 4 (FOC)
```

---

## 每个阶段的里程碑

| 阶段 | 里程碑 | 验证标准 |
|---|---|---|
| Phase 1 | 固定步态行走 | `06_trot_test.py` 稳定走 10 秒 |
| Phase 1 | RL 策略部署 | PPO v7 模型在实机上走 5 秒不倒 |
| Phase 2 | 闭环控制 | 实际角度与目标角度误差 < 1° |
| Phase 2 | 精确 sim2real | 仿真轨迹与实机轨迹偏差 < 10% |
| Phase 3 | 长期稳定 | 连续运行 1 小时无结构损坏 |
| Phase 4 | 力矩控制 | 可做阻抗控制，碰撞时自动卸力 |

---

## 成本汇总

| 阶段 | 累计成本 | 主要投入 |
|---|---|---|
| Phase 1 | ~660 元 | DS3218 + 3D 打印 + Pi |
| Phase 2 | ~1100 元 | 总线舵机 (STS3215) |
| Phase 3 | ~2600 元 | 铝合金结构件 |
| Phase 4 | ~8000+ 元 | FOC 关节电机 |

对比商用产品：XGO Mini2 ~6000 元，Piper ~18000 元。
Phase 3 已接近 XGO 的硬件水平，但软件自主度更高。

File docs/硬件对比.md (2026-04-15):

# 恐龙四足机器人 - 硬件对比分析

与商用机器人产品的对比，帮助理解当前方案的定位和差距。

---

## 对比产品

| 产品 | 类型 | 厂商 | 定位 | 参考价格 |
|---|---|---|---|---|
| **Dino Quadruped (本项目)** | 四足行走机器人 | DIY | 学习/实验 | ~500 元 |
| **蔚蓝 XGO Mini2** | 四足行走机器人 | 蔚蓝智能 (Luwu) | 教育/AI 开发 | ~5000-8000 元 |
| **松灵 Piper** | 6-DOF 机械臂 | 松灵机器人 (AgileX) | 具身智能研发 | ~$2499 (~18000 元) |

---

## 核心参数对比

### 基础规格

| 维度 | Dino (本项目) | XGO Mini2 | Piper |
|---|---|---|---|
| 自由度 | 12 DOF (每腿 3 关节) | 12 DOF (每腿 3 关节) | 6 DOF (6 关节) |
| 重量 | ~1.5kg | ~0.5kg | 4.2kg |
| 尺寸 | 200×110×150mm | 250×145×170mm | 臂展 750mm |
| 负载 | 自身行走 | 自身行走 + 小型夹爪 | 1.5kg 有效载荷 |

### 执行器（最关键差异）

| 维度 | Dino (本项目) | XGO Mini2 | Piper |
|---|---|---|---|
| 执行器类型 | DS3218 模拟舵机 | 总线舵机 (串行通信) | 一体化关节电机 (FOC) |
| 扭矩 | 21 kg·cm | ~4.5 kg·cm | 未公开 (工业级) |
| 控制方式 | PWM 脉宽 (单向) | TTL 串行总线 (双向) | CAN 总线 (双向) |
| 位置反馈 | ❌ 无 | ✅ 磁编码器 | ✅ 高精度编码器 |
| 控制精度 | ±2° (舵机死区) | ±0.1° | ±0.1mm |
| 响应延迟 | ~150ms (60°) | <50ms | <20ms |
| 过载保护 | ❌ 无 (容易烧) | ✅ 电流/温度保护 | ✅ 全面保护 |

### 通信架构

| 维度 | Dino (本项目) | XGO Mini2 | Piper |
|---|---|---|---|
| 总线协议 | I2C (400kHz) | UART → TTL Bus | CAN Bus |
| 驱动芯片 | PCA9685 (外置) | ESP32 (内置) | 关节内置驱动 |
| 更新频率 | ~50Hz (I2C 瓶颈) | ~100Hz | ~1000Hz |
| 通信方向 | 单向 (只能发指令) | 双向 (可读位置/电流) | 双向 (全状态) |
| 拓扑 | Pi → I2C → PCA9685 → PWM → 舵机 | CM4 → UART → ESP32 → TTL → 舵机 | 主控 → CAN → 关节电机 |

### 主控与传感器

| 维度 | Dino (本项目) | XGO Mini2 | Piper |
|---|---|---|---|
| 主控 | 树莓派 3B | 树莓派 CM4 + ESP32 | 兼容 ROS2/CAN 主控 |
| IMU | MPU6050 (GY-521) | 内置 IMU | 关节内编码器 |
| 视觉 | ❌ 无 | ✅ 摄像头 (AI 视觉) | ❌ (外接) |
| 音频 | ❌ 无 | ✅ 麦克风 + 扬声器 | ❌ |
| AI 推理 | CPU (慢) | CM4 + 边缘加速 | 外接算力 |

### 结构与材料

| 维度 | Dino (本项目) | XGO Mini2 | Piper |
|---|---|---|---|
| 机身材料 | 3D 打印 PLA/PETG | 1mm 航空铝合金 | CNC 铝合金 + 复合材料 |
| 腿部材料 | 3D 打印 | ABS 工程塑料 | 铝合金 |
| 装配精度 | ~0.2mm (FDM 打印) | ~0.05mm (机加工) | ~0.02mm (CNC) |
| 刚度 | 有弹性形变 | 刚性好 | 高刚性 |
| 耐久性 | 跑几十次可能断裂 | 长期使用 | 工业级 |

### 软件生态

| 维度 | Dino (本项目) | XGO Mini2 | Piper |
|---|---|---|---|
| 步态控制 | 自研 IK + PPO RL | 内置固定步态 | N/A (机械臂) |
| 编程接口 | Python 直接控制 | Python SDK + 图形编程 | ROS2 + CAN SDK |
| 仿真环境 | PyBullet | 无 (实机为主) | MuJoCo/Isaac Sim |
| 开源程度 | 完全开源 | SDK 开源，固件闭源 | SDK 开源 |
| ROS 支持 | 可自行集成 | 不原生支持 | 原生 ROS2 |

---

## 核心差距分析

### 1. 执行器差距（Sim2Real 最大挑战源）

```
DS3218 (本项目)                  商用总线舵机/关节电机
━━━━━━━━━━━━━━━━━━━━             ━━━━━━━━━━━━━━━━━━━━━━━
PWM 控制，无位置反馈              编码器闭环，实时位置反馈
发出指令后不知道是否到位           随时知道当前角度/电流/温度
响应慢，死区大                    响应快，精度高
容易过热烧毁                     有温度/电流保护
```

影响：
- 仿真中假设"舵机瞬间到位"，实机做不到
- 无法做力矩控制（compliant control）
- sim2real 需要额外的 domain randomization 补偿

### 2. 通信瓶颈

```
I2C + PCA9685 方案:
  - I2C 总线是共享的，12 个舵机串行更新
  - 最高 ~50Hz 控制频率
  - 单向通信，无法读取关节状态

CAN 总线方案 (Piper):
  - 多设备并行通信
  - 轻松 1kHz 控制频率
  - 双向通信，全状态反馈
```

### 3. 结构精度

3D 打印件在装配后的累积误差远大于铝合金机加工件：
- 关节间隙导致步态不精确
- 结构刚度不足导致运动时变形
- 耐久性差，反复运动后磨损加剧

---

## 各产品适用场景

| 场景 | Dino (本项目) | XGO Mini2 | Piper |
|---|---|---|---|
| 学习机器人原理 | ✅ 最佳 | ✅ 好 | ⚠️ 偏贵 |
| RL 算法验证 | ✅ 够用 | ⚠️ 闭源固件受限 | ✅ 支持 |
| sim2real 研究 | ✅ 体验完整流程 | ⚠️ 抽象层太高 | ✅ 精度足够 |
| 具身智能/操作 | ❌ 无夹爪 | ⚠️ 夹爪很小 | ✅ 最佳 |
| 产品原型验证 | ❌ 精度不够 | ⚠️ 尺寸太小 | ✅ 适合 |
| 比赛/展示 | ✅ 外形独特 | ✅ 开箱即用 | ✅ 专业 |

---

## 结论

本项目（Dino Quadruped）的核心价值是**以最低成本跑通"仿真训练 → 实机部署"的完整流程**。
虽然硬件精度和商用产品差 1-2 个数量级，但：
- 全栈可控（从 URDF 建模到 RL 训练到舵机控制）
- 成本极低（~500 元 vs 5000+ 元）
- 学习价值最高（每个环节都需要自己实现）

掌握完整流程后，再升级硬件（总线舵机 → FOC 电机）就是水到渠成。

---

## 参考资料

- [松灵 Piper 官网](https://global.agilex.ai/products/piper)
- [蔚蓝 XGO Mini 规格](https://www.aparobot.com/robots/xgo-mini)
- [XGO-lite2 产品参数](https://wiki.elecfreaks.com/en/microbit/robot/xgo-robot-kit-v2/products-parameters)
- [AgileX Piper 评测](https://www.techeblog.com/agilex-piper-robotic-arm-human-precision/)

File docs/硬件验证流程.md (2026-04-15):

# 恐龙四足机器人 - 硬件验证流程

从收到配件到机器人行走的完整流程指南。
验证脚本位于 `hardware/` 目录，需在树莓派上执行。

---

## 前置准备

### 树莓派环境配置

```bash
# 1. 启用 I2C
sudo raspi-config
# → Interface Options → I2C → Enable
# → 重启

# 2. 安装 Python 依赖
pip3 install adafruit-circuitpython-pca9685 adafruit-circuitpython-servokit smbus2

# 3. 验证 I2C 工具可用
sudo apt install -y i2c-tools
i2cdetect -y 1
```

### 工具清单

- 万用表（调 LM2596 电压、排查断路）
- 十字/内六角螺丝刀（M2、M3）
- 尖嘴钳
- 热风枪或打火机（热缩管）
- 扎带枪
- 游标卡尺（可选，检查 3D 打印件精度）

---

## Phase 0: 来料检验（收件当天）

> 目标：逐个验证每个配件是否正常，退换有问题的件。

### 0.1 电源模块检验

| 步骤 | 操作 | 预期结果 |
|---|---|---|
| 电池 | 充电器充满后量电压 | 8.2~8.4V（2S 锂电满电） |
| LM2596 #1 | 接 7.4V 输入，旋钮调输出 | 万用表量到 5.0V ±0.1V |
| LM2596 #2 | 接 7.4V 输入，旋钮调输出 | 万用表量到 6.0V ±0.1V |
| 开关 | 拨动开关通断 | 万用表通断档有响 |
| XT60 | 检查公母头配对 | 插拔顺畅，不松动 |

⚠️ **LM2596 调压必须在无负载下完成，调好后再接入树莓派/PCA9685。**

### 0.2 I2C 设备检验

先最小接线（树莓派 + PCA9685 + MPU6050），运行扫描：

```bash
python3 hardware/01_i2c_scan.py
```

预期输出：
```
发现 2 个设备:
  0x40 -> PCA9685 (舵机驱动板)
  0x68 -> MPU6050 (IMU 惯性测量单元)

  [OK] PCA9685 (0x40)
  [OK] MPU6050 (0x68)

所有设备就绪，可以继续下一步！
```

**未检测到设备的排查：**

| 现象 | 排查 |
|---|---|
| 完全无设备 | 检查 raspi-config 是否启用 I2C；检查 SDA(Pin3)/SCL(Pin5)/GND(Pin6) 接线 |
| 只有 0x40 | MPU6050 接线问题，确认用 3.3V 供电（不是 5V） |
| 只有 0x68 | PCA9685 接线问题，确认 VCC 接 5V |
| 地址不对 | 检查 MPU6050 的 AD0 引脚是否接 GND（地址 0x68），悬空则为 0x69 |

### 0.3 舵机逐个检验

将舵机逐个接到 PCA9685 的 CH0，测试能否正常转动：

```bash
# 测试单个舵机（全行程扫描）
python3 hardware/02_servo_test.py --channel 0 --sweep
```

每个舵机应该：
- 从 0° 平滑扫到 270° 再扫回来
- 无异响、无卡顿、无抖动
- 转动后能回到归中位置

**12 个舵机全部测试**，记录有问题的编号以便退换。

### 0.4 IMU 检验

```bash
python3 hardware/04_imu_test.py --check
```

将 MPU6050 模块平放在桌面上：
- Z 轴加速度应约 9.8 m/s²
- X/Y 轴漂移应 < 1.5 m/s²
- Roll/Pitch 应接近 0°

---

## Phase 1: 机身框架组装（~1 小时）

> 目标：完成底板 + 铜柱 + 顶板的三明治结构。

```
步骤：
  1. 底板安装 8 根 M3×30 铜柱（螺母侧朝下）
  2. 4 个髋关节舵机用 M3×8 螺丝安装到底板四角
     └─ 注意舵机输出轴方向，参考接线图俯视图
     └─ 先不要完全拧死，留调整余量
  3. 盖上顶板，M3 螺丝固定
  4. 检查框架方正、无扭曲
```

### 验证

- [ ] 8 根铜柱牢固
- [ ] 4 个髋关节舵机固定，输出轴方向正确（参考接线图 S0/S3/S6/S9 位置）
- [ ] 顶板可以拆卸（后续需要接线）

---

## Phase 2: 舵机归中 → 腿部组装（~2 小时）

> 目标：先让舵机电气归中，再安装机械结构，保证零位一致。

### 2.1 全部舵机归中（关键步骤）

⚠️ **此步骤必须在安装舵机角（horn）之前完成！**

```bash
# 接好 PCA9685 和 12 个舵机的线
# 确保 6V 供电已接入 PCA9685 V+ 端
python3 hardware/03_servo_center_all.py
```

所有舵机将转到 135°（中位）。确认全部停稳后：

1. **安装舵机角**：将 horn 安装到舵机轴上，使腿部指向正下方
2. 用 M2 自攻螺丝锁紧舵机角
3. 此时机械零位 = 电气零位

### 2.2 单腿组装（×4 条腿）

每条腿从上到下：

```
髋关节舵机（已装在底板）
  ↓ 舵机角
髋关节支架（hip_bracket）── 提供侧向偏移
  ↓
肩关节舵机 ── 装入 U 型支架
  ↓ 舵机角
大腿连杆（upper_leg, 100mm）── MR105ZZ 轴承做对侧支撑
  ↓
膝关节舵机 ── 装在大腿/小腿连接处
  ↓ 舵机角
小腿连杆（lower_leg, 100mm）
  ↓
硅胶脚垫 ── 压入或粘合
```

### 验证

- [ ] 每条腿 3 个关节可以自由活动，无卡滞
- [ ] 舵机角锁紧，不松动
- [ ] 四条腿长度一致（大腿 100mm + 小腿 100mm）
- [ ] 轴承安装到位，关节无侧向晃动

---

## Phase 3: 电子接线（~1.5 小时）

> 目标：完成全部电气连接，参照 `docs/接线图.md`。

### 接线顺序

```
1. 电源线路（14AWG 硅胶线）
   电池 XT60 → 开关 → 分两路:
   ├── LM2596 #1 (7.4V→5V) → 树莓派 5V/GND
   └── LM2596 #2 (7.4V→6V) → PCA9685 V+ 端

2. I2C 总线（杜邦线）
   树莓派 Pin3(SDA) ─┬→ PCA9685 SDA
                      └→ MPU6050 SDA
   树莓派 Pin5(SCL) ─┬→ PCA9685 SCL
                      └→ MPU6050 SCL
   树莓派 Pin6(GND)  ─┬→ PCA9685 GND
                       ├→ MPU6050 GND
                       └→ LM2596 共地

3. 舵机线（30cm 延长线）
   CH0~CH11 按接线图顺序连接
   每条腿 3 根线束扎在一起，每隔 3cm 用扎带固定

4. 电源供电
   PCA9685 VCC ← 5V（逻辑供电）
   MPU6050 VCC ← 3.3V（树莓派 Pin1）
```

### 接线注意事项

- **I2C 信号线远离舵机电源线**，防止电磁干扰
- 电源线 LM2596 #2 → PCA9685 V+ **尽量短**（<5cm），减少压降
- 所有连接点套热缩管，防止短路
- GND 必须共地（树莓派、PCA9685、MPU6050、LM2596 共用一个地）

### 验证

接线完成后，**先不接电池**，用万用表检查：

- [ ] 5V 供电路径无短路（万用表电阻档量 5V 和 GND 之间）
- [ ] 6V 供电路径无短路
- [ ] I2C SDA/SCL 无短路到 GND

确认无误后接入电池，运行：

```bash
python3 hardware/01_i2c_scan.py  # 再次确认 I2C 设备
```

---

## Phase 4: 校准与验证

> 目标：让机器人站起来，走起来。

### 4.1 IMU 安装校验

将 MPU6050 安装在机身中心后：

```bash
python3 hardware/04_imu_test.py --check
```

确认：
- 芯片面朝上，X 轴朝机头方向
- Z 轴读数约 +9.8 m/s²
- 机身水平时 Roll/Pitch 接近 0°

### 4.2 站立测试

```bash
python3 hardware/05_stand_test.py
```

**检查项：**

| 检查项 | 方法 | 预期 |
|---|---|---|
| 四脚着地 | 目视 | 四个脚垫均匀接触地面 |
| 机身水平 | IMU 或水平尺 | Roll/Pitch < 3° |
| 站立高度 | 尺量地面到底板 | 约 150mm |
| 稳定性 | 轻推机身 | 不倒、无晃动 |

### 4.3 舵机偏移校准（如果站不正）

```bash
python3 hardware/05_stand_test.py --calibrate
```

进入交互模式，逐个微调关节偏移量：

```
校准> fl_shoulder +30    # 左前肩关节正转 30μs
校准> show               # 查看当前偏移
校准> stand              # 重新站立查看效果
校准> save               # 满意后保存偏移值
```

将最终偏移值更新到 `hardware/servo_config.py` 的 `SERVO_OFFSET_US` 字典中。

### 4.4 慢速行走测试（首次必须用慢速）

```bash
python3 hardware/06_trot_test.py --slow --duration 3
```

⚠️ **安全注意：**
- 首次行走请在平坦桌面/地面上
- 手要放在机器人旁边，随时准备接住
- 准备好随时拔电池 XT60 头紧急断电

**观察项：**
- 四条腿是否交替抬放（对角步态）
- 是否向前移动（不是原地打转）
- 有无舵机异响（过载、卡顿）

### 4.5 正常速度行走

慢速测试通过后：

```bash
python3 hardware/06_trot_test.py --duration 10
```

### 4.6 参数调优

如果行走不稳，可调整参数：

| 问题 | 调整方法 |
|---|---|
| 走路画圈/偏转 | 检查 `servo_config.py` 的 `SERVO_DIRECTION`，右侧腿应为 -1 |
| 步态不协调 | 降低频率 `--freq 30`，增大周期 `--period 0.8` |
| 抬腿不够高 | 增大 `--step-height 0.04` |
| 步幅太大摔倒 | 减小 `--step-length 0.02` |
| 舵机抖动 | 供电不足，检查 LM2596 #2 输出电流，必要时换 XL4016 |

---

## 常见问题排查

| 现象 | 可能原因 | 解决方法 |
|---|---|---|
| I2C 扫描不到设备 | 未启用 I2C / 接线错误 | `raspi-config` 启用；检查 SDA/SCL/GND |
| 舵机不转 | 6V 未供电 / 通道接错 | 检查 PCA9685 V+ 端有 6V；核对通道号 |
| 舵机抖动/嗡嗡响 | 供电电流不足 | LM2596 最大 3A，12 舵机峰值 12A → 换 XL4016 或加大电容 |
| 站不稳/倾斜 | 舵机角安装偏了 | `05_stand_test.py --calibrate` 微调偏移 |
| 走路画圈 | 左右腿方向不一致 | 修改 `servo_config.py` 的 `SERVO_DIRECTION` |
| IMU 数据乱跳 | 电磁干扰 | I2C 线远离舵机电源线；加 100nF 去耦电容 |
| 树莓派突然重启 | 电压跌落 | 舵机运动时电池压降，5V 不够 → LM2596 输入加 470μF 电容 |

---

## 验证脚本一览

| 脚本 | 用途 | 何时运行 |
|---|---|---|
| `hardware/01_i2c_scan.py` | I2C 设备扫描 | 接线后第一步 |
| `hardware/02_servo_test.py` | 单舵机测试 | 来料检验 |
| `hardware/03_servo_center_all.py` | 全部舵机归中 | 组装腿部之前 |
| `hardware/04_imu_test.py` | IMU 数据验证 | IMU 安装后 |
| `hardware/05_stand_test.py` | 站立姿态 / 校准 | 组装完成后 |
| `hardware/06_trot_test.py` | Trot 步态行走 | 站立验证通过后 |
| `hardware/servo_config.py` | 舵机配置（共用） | 校准后更新偏移量 |

---

## 下一步：Sim2Real Transfer

硬件验证完成后，进入 sim2real 阶段：

1. **System Identification**：用实测数据修正仿真参数
   - 称量实际零件重量 → 更新 URDF mass/inertia
   - 测量舵机响应曲线 → 更新仿真关节动力学
   - 测量 MPU6050 噪声 → 更新仿真传感器模型

2. **Domain Randomization**：在 PyBullet 训练时加入随机扰动
   - 质量 ±15%、摩擦 0.4~1.0、动作延迟 1-3 步

3. **RL 策略部署**：用 v7 PPO 模型替代固定步态生成器
   - 树莓派上用 ONNX Runtime 推理
   - 50Hz 控制循环：IMU 读取 → 模型推理 → 舵机输出

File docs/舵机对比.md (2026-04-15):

# 恐龙四足机器人 - 舵机对比与驱动原理

DS3218 (当前方案) vs STS3215 (升级方案) 的完整技术对比。

---

## 1. 舵机内部结构

### DS3218 (PWM 模拟舵机)

```
┌─────────────────────────────────────┐
│  ┌───────┐                          │
│  │ 直流   │──► 齿轮组 ──► 输出轴 ──►── 舵机角(horn)
│  │ 电机   │    (减速)     (扭矩放大)     ↓
│  └───────┘                          │   连接腿部连杆
│       ↑                             │
│  ┌─────────┐   ┌────────────┐       │
│  │ 驱动电路  │←──│ 电位器      │       │  电位器装在输出轴上
│  │ (H桥)   │   │ (位置传感器) │       │  轴转多少度，电阻值变多少
│  └────┬────┘   └────────────┘       │
│       ↑                             │
│  ┌─────────┐                        │
│  │ 控制芯片  │←── PWM 信号输入         │  来自 PCA9685
│  └─────────┘                        │
└─────────────────────────────────────┘
   棕色(GND)  红色(6V)  橙色(PWM信号)
```

### STS3215 (TTL 总线舵机)

```
┌─────────────────────────────────────┐
│  ┌───────┐                          │
│  │ 直流   │──► 齿轮组 ──► 输出轴 ──►── 舵机角(horn)
│  │ 电机   │    (减速)     (扭矩放大)     ↓
│  └───────┘                          │   连接腿部连杆
│       ↑                             │
│  ┌─────────┐   ┌────────────┐       │
│  │ FOC/H桥 │←──│ 磁编码器    │       │  磁铁粘在输出轴
│  │ 驱动    │   │ (AS5600)   │       │  霍尔芯片非接触感应
│  └────┬────┘   └─────┬──────┘       │
│       ↑              │ 12-bit 数字信号│
│  ┌─────────┐         │              │
│  │ STM32   │←────────┘              │
│  │ 微控制器 │                        │
│  │         │←──► TTL 串行总线 ◄──►   │  双向通信
│  └─────────┘    (半双工 UART)        │
└─────────────────────────────────────┘
   黑色(GND)  红色(VIN)  黄色(DATA)
```

---

## 2. 位置传感器对比：电位器 vs 磁编码器

```
电位器 (DS3218)                     磁编码器 (STS3215)
━━━━━━━━━━━━━━━━━━━                ━━━━━━━━━━━━━━━━━━━━━━━━

 ┌────────┐                         ┌────────┐
 │ 碳膜电阻 │ ← 电刷滑动              │  磁铁   │ ← 粘在输出轴上
 │ 片     │   接触磨损               │ (径向充磁)│  无接触，不磨损
 └───┬────┘                         └───┬────┘
     │ 模拟电压信号                        │ 磁场
     ↓                                   ↓
 ADC 采样                            ┌────────┐
 ~10bit 精度                         │ 霍尔/磁 │ ← 感应芯片 (AS5600)
 ±2° 分辨率                          │ 阻传感器 │   非接触式
                                    └───┬────┘
  缺点:                                  │ 数字信号
  - 机械接触，寿命有限                       ↓
  - 精度随磨损下降                      12-bit 数字输出
  - 有死区和非线性                      4096 步/圈
  - 只在内部使用，外部读不到              ±0.088° 分辨率

                                     优点:
                                     - 无接触，寿命极长
                                     - 精度恒定，不退化
                                     - 无死区
                                     - 数据可通过总线读出
```

---

## 3. 通信链路对比

### DS3218 + PCA9685 (单向 PWM)

```
Python                PCA9685              DS3218 内部
  │                     │                    ┌──────────────┐
  │  "转到135°"         │  PWM 1500μs        │  控制芯片      │
  │ ──I2C写寄存器──►   │ ──脉冲信号──►      │    ↓          │
  │                     │                    │  目标=135°    │
  │                     │                    │  电位器=90°   │
  │                     │                    │  误差=+45°    │
  │                     │                    │    ↓ 驱动电机  │
  │                     │                    │  电位器=135°  │
  │  到位了吗？          │                    │  误差=0 停止  │
  │  不知道 ❌           │                    └──────────────┘
  │  只能"信任"         │                    (闭环在内部，对外是黑盒)
```

### STS3215 总线舵机 (双向 TTL)

```
Python              UART 总线 (半双工)          STS3215 内部
  │                     │                    ┌───────────────────┐
  │                     │                    │  微控制器 (STM32)   │
  │  ① 写位置指令        │  TX 数据包           │    ↓               │
  │  sts.write_pos(     │  [FF FF 01 03      │  目标=2048         │
  │    id=1, pos=2048)  │   1E 00 08 xx]     │                   │
  │ ────────────────►  │ ────────────────►  │  磁编码器读数=1024  │
  │                     │                    │  误差=+1024        │
  │                     │                    │    ↓ FOC/H桥驱动   │
  │                     │                    │  电机转动...        │
  │                     │                    │  磁编码器读数=2040  │
  │                     │                    │  误差=+8 继续微调   │
  │                     │                    │  磁编码器读数=2048  │
  │  ② 读实际位置        │  TX 请求             │  误差=0 到位       │
  │  pos = sts.read_pos │ ────────────────►  │                   │
  │    (id=1)           │                    │    ↓               │
  │                     │  RX 返回数据         │  返回: pos=2048    │
  │  pos = 2048 ✅      │ ◄────────────────  │  返回: speed=0     │
  │  确认到位!           │                    │  返回: load=12%    │
  │                     │                    │  返回: temp=38°C   │
  └─────────────────────┘                    └───────────────────┘
```

---

## 4. PWM 信号编码原理

PCA9685 发出的 PWM 信号用**脉冲宽度**表示目标角度：

```
20ms 周期 (50Hz)
├──────────────────────────────────────────────┤

 500μs 脉宽 = 0°
 ┌──┐
 │  │
─┘  └───────────────────────────────────────────

 1500μs 脉宽 = 135° (中位)
 ┌──────┐
 │      │
─┘      └───────────────────────────────────────

 2500μs 脉宽 = 270°
 ┌──────────┐
 │          │
─┘          └───────────────────────────────────

脉冲越宽 → 角度越大
舵机控制芯片只看脉宽，不看周期
```

### 角度换算公式

```
DS3218 (PWM):
  pulse_us = 500 + (angle_deg / 270) × 2000
  pca_value = (pulse_us / 20000) × 4096

STS3215 (总线):
  position = (angle_deg / 360) × 4096    // 12-bit, 0-4095
  直接发数字值，无需模拟转换
```

---

## 5. 核心参数对比

### 基础规格

| 参数 | DS3218 (当前) | STS3215 (升级) |
|---|---|---|
| 扭矩 | 21 kg·cm @ 6V | 15 kg·cm @ 7.4V |
| 角度范围 | 270° | 360° (可连续旋转) |
| 工作电压 | 4.8-6.8V | 6-12.6V |
| 齿轮材质 | 金属齿轮 | 金属齿轮 |
| 重量 | ~60g | ~56g |
| 尺寸 | 40×20×40.5mm | 40×20×40.5mm |
| 单价 | ~25 元 | ~60 元 |
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

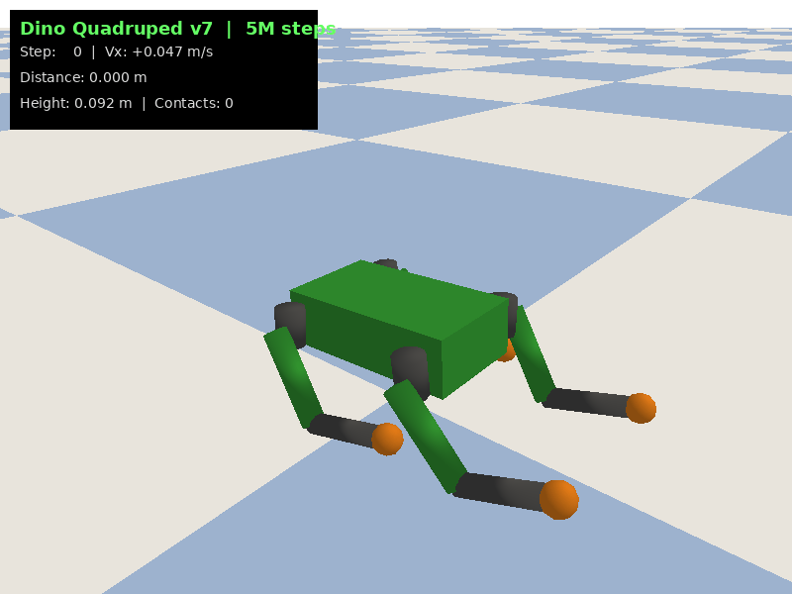
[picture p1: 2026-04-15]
eval_output/v7_5M_walk.gif

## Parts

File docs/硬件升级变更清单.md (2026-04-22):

# 恐龙四足机器人 - 硬件升级变更清单

为支持 120Hz 控制频率（RL v7 策略要求），从 Phase 1 升级到 Phase 2 的完整变更清单。

---

## 升级背景

RL v7 策略在仿真中的控制频率：
```
PyBullet 物理步进: 240Hz (dt = 1/240)
action_repeat:     2
控制频率:          240 / 2 = 120Hz
控制周期:          8.33ms
```

当前硬件 PCA9685 更新 12 路舵机需 ~12ms，超过 8.33ms 周期，**物理上无法支持 120Hz**。

---

## 一、采购变更

### 新增/替换

| 序号 | 操作 | 旧件 | 新件 | 数量 | 单价 | 费用变化 |
|---|---|---|---|---|---|---|
| H1 | 替换 | DS3218 舵机 | STS3215 总线舵机 | 12 | ~60 元 | +(60-25)×12 = +420 元 |
| H2 | 去掉 | PCA9685 驱动板 | - | 1 | - | -15 元 |
| H3 | 新增 | - | USB 转 TTL 板 (FT232 芯片) | 1 | ~15 元 | +15 元 |
| H4 | 替换 | 树莓派 3B | 树莓派 4B (2GB) | 1 | ~350 元 | +(350-200) = +150 元 |
| H5 | 可去掉 | LM2596 #2 (6V 舵机供电) | 7.4V 电池直供 | 1 | - | -5 元 |
| | | | | | **净增** | **~565 元** |

### 保留不变

| 组件 | 说明 |
|---|---|
| MPU6050 (GY-521) | I2C 总线空闲后读取更快更稳 |
| LM2596 #1 | 仍给 Pi 4B 供 5V |
| 2S 7.4V 电池 | STS3215 支持 6~12.6V，直供 |
| 3D 打印结构件 | STS3215 与 DS3218 外形完全兼容 |
| 所有紧固件/轴承 | 机械结构不变 |

---

## 二、接线变更

### 去掉的线路

```
✖ Pi → PCA9685 的 I2C 线 (SDA/SCL/VCC/GND 共 4 根杜邦线)
✖ PCA9685 V+ 端 6V 供电线 (来自 LM2596 #2)
✖ 12 根独立 PWM 信号线 (PCA9685 CH0~CH11 → 各舵机橙色信号线)
✖ LM2596 #2 的输入/输出线 (可选去掉)
```

### 新增的线路

```
✚ Pi USB 口 → USB 转 TTL 板 (1 根 USB 线, ~10cm)
✚ TTL 板 DATA 引脚 → 第一个舵机的数据口 (1 根信号线, ~8cm)
✚ 舵机间菊花链 (STS3215 自带双排线接口，直接串联)
✚ 电池 7.4V → 舵机电源干线 (1 对红黑 14AWG, 并联到各舵机)
```

### 接线对比

```
旧方案 (PCA9685 + PWM, 42 根线):
  Pi ──SDA/SCL──► PCA9685 ──CH0~CH11──► 12×DS3218 (每个3线)
                    ↑
                   6V (LM2596#2)

新方案 (STS3215 + TTL 总线, 4 根主线):
  Pi ──USB──► TTL板 ──DATA──► 舵机1 ══► 舵机2 ══► ... ══► 舵机12
                                ↑                            ↑
  电池 7.4V ───────── VIN 电源干线 (并联供电) ────────────────┘
```

### I2C 总线变化

```
旧: Pi I2C 总线挂载 PCA9685(0x40) + MPU6050(0x68) → 总线繁忙，互相争抢
新: Pi I2C 总线只剩 MPU6050(0x68) → 总线空闲，IMU 读取更快更稳定
```

---

## 三、供电架构变更

```
旧方案:
  电池 7.4V ─┬─► LM2596#1 ──► 5V (Pi 3B + PCA9685 逻辑供电)
             └─► LM2596#2 ──► 6V (DS3218 舵机供电，经 PCA9685 V+ 分配)

新方案:
  电池 7.4V ─┬─► LM2596#1 ──► 5V (仅 Pi 4B + MPU6050)
             └─► 直供 7.4V ──► STS3215 舵机电源干线 (无需降压)

变化:
  ✖ 去掉 LM2596#2 (STS3215 工作电压 6~12.6V，7.4V 直供)
  ⚠️ 电源干线需 14AWG 硅胶线，总线峰值电流可达 12A+
  ⚠️ 电池端并联 470μF/16V 电解电容，防止舵机瞬态电流导致电压跌落
```

---

## 四、机械结构变更

```
DS3218 vs STS3215 外形:
  尺寸:    40 × 20 × 40.5mm  vs  40 × 20 × 40.5mm  ✅ 完全一样
  重量:    60g               vs  56g                ✅ 更轻
  安装孔:  标准舵机孔位                               ✅ 兼容
  舵机角:  25T 花键                                  ✅ 通用

结论: 机械结构零改动，舵机直接替换，螺丝孔位一致
```

---

## 五、软件变更

### 修改的文件

| 文件 | 改动内容 | 工作量 |
|---|---|---|
| `hardware/servo_config.py` | PWM 参数全部替换为总线 ID + 位置映射 (0-4095)；去掉 PCA9685 相关常量；新增串口配置 | 中 |
| `hardware/01_i2c_scan.py` | 去掉 PCA9685 (0x40) 检查；新增 UART 串口扫描逻辑 | 小 |
| `hardware/02_servo_test.py` | `ServoKit` → `SCServo SMS_STS`；加入反馈读取 (位置/温度/负载) | 中 |
| `hardware/03_servo_center_all.py` | 同上，改用 `SyncWritePosEx` 批量归中 | 小 |
| `hardware/05_stand_test.py` | 改用 SCServo 驱动；校准模式加入位置反馈验证 | 中 |
| `hardware/06_trot_test.py` | 改用 `SyncWritePosEx`；加入实时位置/温度监控；控制频率提升到 120Hz | 中 |

### 新增的文件

| 文件 | 用途 |
|---|---|
| `hardware/servo_bus.py` | STS3215 总线驱动封装 (初始化/读写/SyncWrite/SyncRead) |
| `hardware/servo_id_setup.py` | 给 12 个舵机逐个设置 ID (首次配置，一次性操作) |
| `hardware/servo_monitor.py` | 实时显示 12 路位置/负载/温度仪表盘 |
| `hardware/servo_response_test.py` | 自动测量舵机阶跃响应曲线 (用于 System Identification) |
| `rl/deploy_real.py` | 实机 RL 策略部署脚本 (120Hz 控制循环) |

### 不需要改的文件

| 文件 | 原因 |
|---|---|
| `hardware/04_imu_test.py` | MPU6050 保留，代码不变 |
| `rl/dino_env.py` | 仿真环境代码，不涉及硬件 |
| `rl/train_ppo.py` | 训练代码，不涉及硬件 |
| `scripts/sim_standalone.py` | 仿真脚本，不涉及硬件 |
| `urdf/dino.urdf` | 模型文件不变 |

### 核心代码差异

```python
# ===== 旧: servo_config.py =====
PCA9685_ADDR = 0x40
PWM_FREQ = 50
SERVO_MIN_US = 500     # 0°
SERVO_MID_US = 1500    # 135°
SERVO_MAX_US = 2500    # 270°

CHANNEL_MAP = {
    "fl_hip": 0, "fl_shoulder": 1, "fl_knee": 2,
    # ...
}

def us_to_pca(pulse_us):
    return int((pulse_us / 20000.0) * 4096)

# ===== 新: servo_config.py =====
UART_PORT = "/dev/ttyUSB0"
BAUDRATE = 1_000_000        # 1Mbps
SERVO_POS_MIN = 0           # 0°
SERVO_POS_MID = 2048        # 180°
SERVO_POS_MAX = 4095        # 360°

SERVO_IDS = {
    "fl_hip": 1, "fl_shoulder": 2, "fl_knee": 3,
    "fr_hip": 4, "fr_shoulder": 5, "fr_knee": 6,
    "rl_hip": 7, "rl_shoulder": 8, "rl_knee": 9,
    "rr_hip": 10, "rr_shoulder": 11, "rr_knee": 12,
}

def rad_to_pos(angle_rad, joint_name):
    """弧度 → STS3215 位置值 (0-4095)"""
    direction = SERVO_DIRECTION[joint_name]
    offset = SERVO_OFFSET[joint_name]
    pos = SERVO_POS_MID + int(angle_rad * direction * 4096 / (2 * math.pi)) + offset
    return max(SERVO_POS_MIN, min(SERVO_POS_MAX, pos))
```

```python
# ===== 旧: 控制循环 (06_trot_test.py) =====
kit = ServoKit(channels=16)
for ch in range(12):                        # 串行更新，~12ms
    kit.servo[ch].angle = target_angles[ch]

# ===== 新: 控制循环 (06_trot_test.py) =====
sts = SMS_STS()
sts.open_port("/dev/ttyUSB0", 1000000)

# SyncWrite 一次更新 12 路，~1.5ms
sts.SyncWritePosEx(
    ids=[1,2,3,4,5,6,7,8,9,10,11,12],
    positions=target_positions,
    speeds=[0]*12,    # 0=最快速到达
    accs=[0]*12
)

# 还能读反馈
positions = [sts.ReadPos(i) for i in range(1,13)]      # 实际位置
temps = [sts.ReadTemperature(i) for i in range(1,13)]   # 温度
```

### 依赖库变更

```bash
# 去掉
pip3 uninstall adafruit-circuitpython-pca9685 adafruit-circuitpython-servokit

# 新增
pip3 install SCServo           # Feetech STS 系列 Python SDK
pip3 install onnxruntime       # RL 推理 (Pi 4B 上)

# 保留
pip3 install smbus2            # MPU6050 仍用 I2C
```

---

## 六、首次配置步骤

DS3218 即插即用，STS3215 需要先给每个舵机设置唯一 ID：

```bash
# 1. 每次只接一个舵机到总线
# 2. 运行设置脚本
python3 hardware/servo_id_setup.py --id 1    # 第一个舵机设为 ID=1
# 3. 断开，换下一个
python3 hardware/servo_id_setup.py --id 2    # 设为 ID=2
# ... 重复 12 次

# 4. 全部接到菊花链，验证
python3 hardware/servo_id_setup.py --scan
# 预期输出: Found 12 servos: [1, 2, 3, 4, 5, 6, 7, 8, 9, 10, 11, 12]

# 5. 给每个舵机贴标签 (ID + 关节名)
```

---

## 七、风险评估

| 风险 | 概率 | 影响 | 缓解措施 |
|---|---|---|---|
| STS3215 协议不熟导致调试时间长 | 中 | 低 | SCServo SDK 文档齐全，有完整示例 |
| USB 转 TTL 芯片延迟过大 | 低 | 高 | 选 FT232 芯片（延迟 <1ms），避免 CH340 |
| 7.4V 直供 12 路瞬态电流 >10A | 中 | 中 | 30A 放电倍率电池 + 470μF 电容 |
| Pi 4B 长时间 120Hz 推理发热 | 中 | 低 | 加铝散热片 + 5V 小风扇 (~10 元) |
| 舵机 ID 冲突导致总线混乱 | 低 | 高 | 严格逐个配置，配好后贴标签 |
| STS3215 扭矩比 DS3218 小 (15 vs 21 kg·cm) | 低 | 低 | 机器人只 1.5kg，15kg·cm 余量充足 |

---

## 八、变更总结

```
采购:  12×STS3215 + 1×USB转TTL(FT232) + 1×Pi4B           ~565 元
去掉:  PCA9685 + LM2596#2 + 12×DS3218
接线:  42根线 → 4根主线 (大幅简化)
机械:  零改动 (舵机外形完全兼容)
软件:  改 6 个文件 + 新增 5 个文件
配置:  需逐个设舵机 ID (一次性，~30 分钟)
收益:  I2C 12ms → UART 1.5ms，解锁 120Hz 实机控制 + 位置反馈闭环
```

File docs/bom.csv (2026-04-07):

Category | Part | Spec | Qty | Unit_Price_CNY | Total_CNY | Taobao_Keyword | Priority | Notes
Electronics | DS3218 Servo | 270° 20kg metal gear | 12 | 40 | 480 | DS3218 舵机 20kg 270度 金属齿 | P0 | Core actuators
Electronics | PCA9685 Servo Driver | 16-ch PWM I2C | 1 | 15 | 15 | PCA9685 舵机驱动板 16路 | P0 | Servo controller
Electronics | MPU6050 IMU | GY-521 6-axis | 1 | 8 | 8 | MPU6050 GY-521 模块 | P0 | Balance feedback
Power | 2S LiPo Battery | 7.4V 5000mAh 30C XT60 | 1 | 120 | 120 | 2S锂电池 7.4V 5000mah XT60 | P0 | Main power
Power | Balance Charger | B3 2S/3S | 1 | 35 | 35 | B3平衡充电器 2S 3S | P0 | Battery charger
Power | LM2596 Buck Converter | DC-DC adjustable | 2 | 8 | 16 | LM2596 降压模块 可调 | P0 | 5V for Pi + 6V for servos
Power | Power Switch | 10A toggle | 1 | 5 | 5 | 大电流拨动开关 10A | P0 | Main power switch
Power | XT60 Connectors | Male+Female pair | 4 | 2.5 | 10 | XT60 接头 公母 | P0 | Battery connection
Power | Silicone Wire 14AWG | Red+Black 1m each | 2 | 5 | 10 | 14AWG 硅胶线 红黑 | P0 | Power wiring
Wiring | Servo Extension Cable | 30cm | 12 | 1.7 | 20 | 舵机延长线 30cm | P0 | Servo to PCA9685
Wiring | Dupont Wires | 40P M-F + F-F | 2 | 7.5 | 15 | 杜邦线 40P 公母 母母 | P0 | I2C + GPIO
Structure | Acrylic Plate | 3mm laser cut 200×110mm | 2 | 50 | 100 | 亚克力 激光切割 来图定制 3mm | P1 | Body top+bottom plates
Structure | Servo U-Bracket | Aluminum for DS3218 | 12 | 5 | 60 | 舵机支架 铝合金 U型 标准 | P1 | Servo mounting
Structure | 3D Print Parts | PLA hip+leg brackets | 1 | 80 | 80 | 3D打印 PLA 来图定制 | P1 | Hip brackets + leg links
Structure | MR105ZZ Bearing | 5×10×4mm miniature | 16 | 2 | 32 | MR105ZZ 微型轴承 5x10x4 | P1 | Joint dual-support
Structure | Silicone Foot Pad | Hemisphere 15mm | 4 | 3 | 12 | 硅胶脚垫 半球 15mm | P1 | Ground contact
Fasteners | M3 Screw Kit | M3×8 + M3×12 socket cap | 1 | 25 | 25 | M3 不锈钢内六角螺丝套装 | P1 | Assembly
Fasteners | M3×30 Standoff | Brass M/F | 8 | 1.5 | 12 | M3×30 铜柱 六角隔离柱 | P1 | Body plate spacing
Fasteners | Zip Ties + Heat Shrink | Mixed pack | 1 | 10 | 10 | 扎带 热缩管 混装 | P1 | Cable management
Fasteners | Velcro Strap | 20mm width | 2 | 3 | 6 | 魔术贴绑带 20mm | P1 | Battery mounting
Optional | Battery Alarm | 2S low-voltage buzzer | 1 | 5 | 5 | 2S低压报警器 锂电池 | P2 | Battery protection
Optional | BNO055 IMU | 9-axis absolute orientation | 1 | 80 | 80 | BNO055 九轴 IMU 模块 | P2 | Upgrade from MPU6050
Optional | USB Camera | Wide-angle 720p | 1 | 40 | 40 | USB广角摄像头 720P 免驱 | P2 | Vision (Month 3)
Optional | Pi Heatsink | Aluminum adhesive | 1 | 5 | 5 | 树莓派散热片 铝 贴片 | P2 | Thermal management

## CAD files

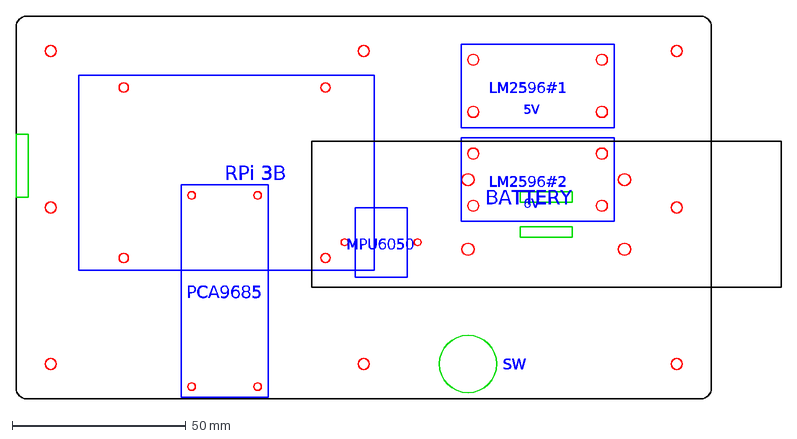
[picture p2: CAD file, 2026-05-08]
cad/body_top.dxf
RPi 3B
PCA9685
MPU6050
BATTERY
LM2596#1
5V
LM2596#2
6V
SW

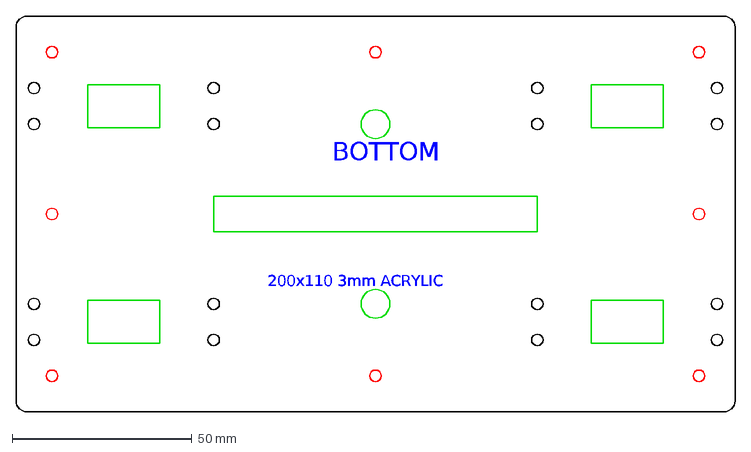
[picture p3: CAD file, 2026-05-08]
cad/body_bottom.dxf
BOTTOM
200x110 3mm ACRYLIC

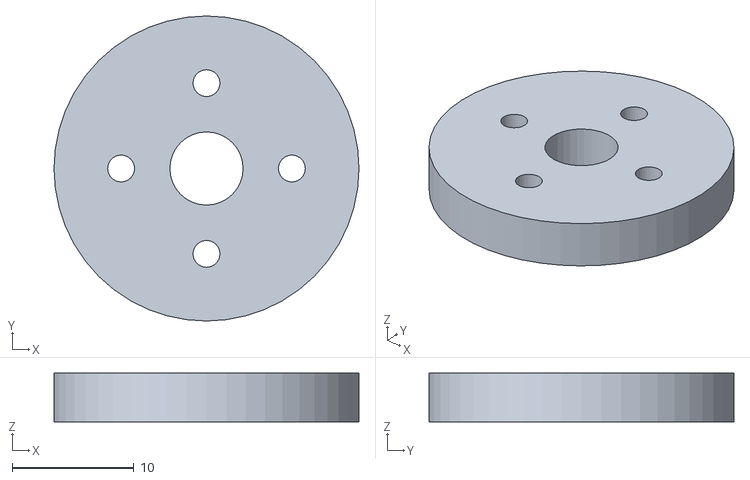
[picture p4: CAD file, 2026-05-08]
cad/horn_adapter.stl
25.0 x 25.0 x 4.00

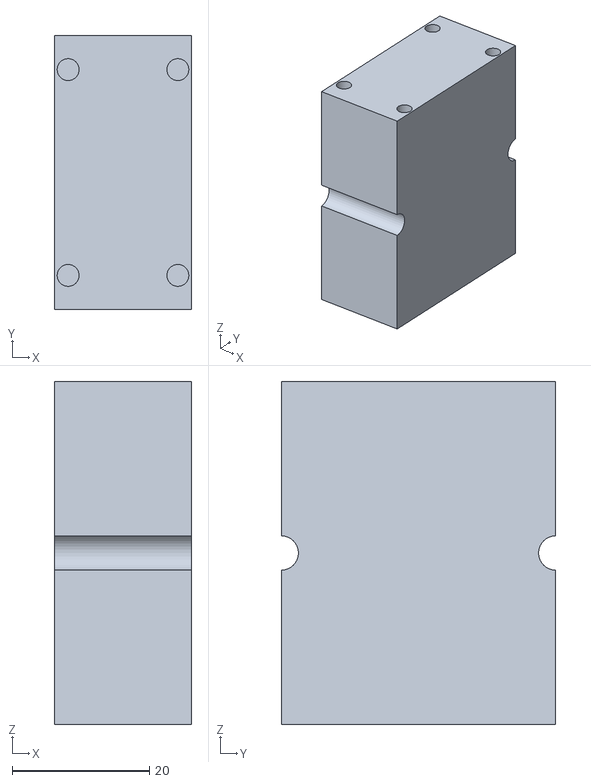
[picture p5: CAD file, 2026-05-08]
cad/hip_bracket.stl
20.0 x 40.0 x 50.0

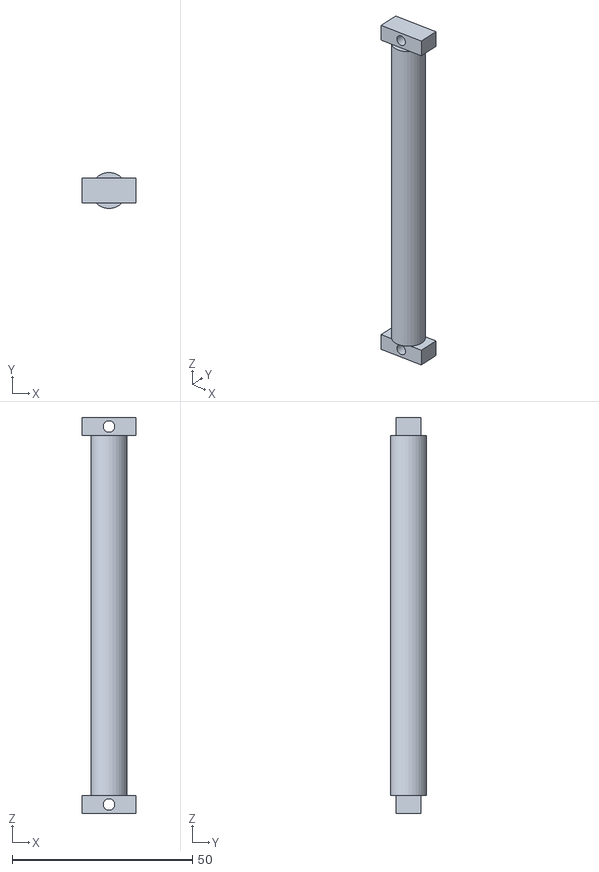
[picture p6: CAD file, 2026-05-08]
cad/upper_leg.stl
15.0 x 10.0 x 110.0

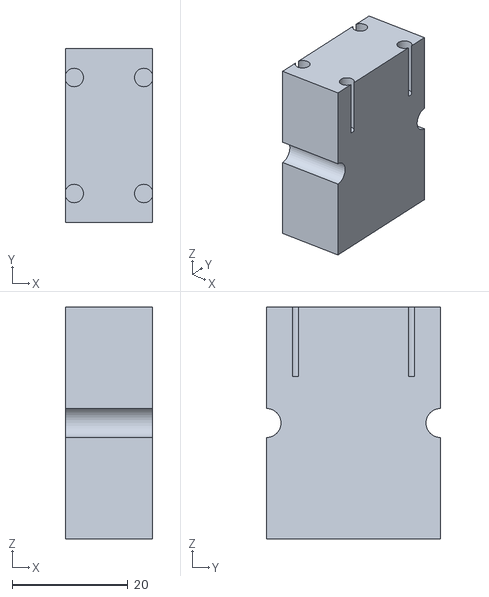
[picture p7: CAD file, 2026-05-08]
cad/knee_bracket.stl
15.0 x 30.0 x 40.0

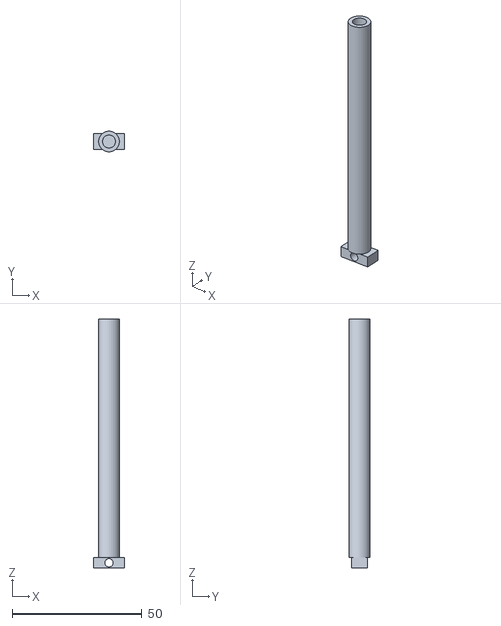
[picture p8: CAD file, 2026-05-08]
cad/lower_leg.stl
12.0 x 8.00 x 96.0

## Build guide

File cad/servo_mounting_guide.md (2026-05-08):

# 舵机U型槽固定方式说明

## 📐 U型槽结构原理

U型槽（U-shaped bracket）是机器人中最常见的舵机固定方式，通过三面包围舵机本体来实现稳固安装。

### 基本结构

```
侧视图:
    ┌─────────────────┐  ← 顶部开口
    │                 │
    │   ┌─────────┐   │  ← 舵机本体
    │   │ DS3218  │   │
    │   │         │   │
    │   └─────────┘   │
    └─────────────────┘  ← 底部

俯视图:
    ┌───┐         ┌───┐
    │   │         │   │  ← 两侧壁
    │   │  舵机   │   │
    │   │         │   │
    └───┘         └───┘
```

---

## 🔩 DS3218 舵机固定方式

### 1. 舵机结构特点

DS3218 舵机有两个金属安装耳（mounting flanges），从舵机本体两侧伸出：

```
正视图（从舵机前方看）:

    安装耳                安装耳
      ↓                    ↓
    ┌──┐                ┌──┐
    │  │  ┌──────────┐  │  │
    │●─┼──┤          ├──┼─●│  ← ● 表示安装孔 (Φ3mm)
    │  │  │  舵机    │  │  │
    │  │  │  本体    │  │
    │●─┼──┤          ├──┼─●│
    │  │  └──────────┘  │  │
    └──┘                └──┘
         ← 48mm 孔距 →

每个安装耳上有 2 个 Φ3mm 螺丝孔
垂直间距：10mm (标准 DS3218)
```

### 2. U型槽工作原理

**步骤 1: 舵机从顶部放入U型槽**

```
侧视图:
         ↓ 放入方向
    ┌─────────────────┐
    │                 │
    │   ┌─────────┐   │
    │   │ 舵机    │   │  ← 舵机本体卡在槽内
    │   │         │   │
    │   └─────────┘   │
    └─────────────────┘
    
U型槽尺寸:
- 内宽：~22mm (舵机本体宽度 20mm + 2mm间隙)
- 深度：~45mm (舵机高度 41mm + 4mm余量)
- 长度：~42mm (舵机长度 40.5mm + 1.5mm间隙)
```

**步骤 2: 安装耳伸出U型槽外侧**

```
俯视图:

    ┌───┐         ┌───┐
    │   │  舵机   │   │
    │●──┼─────────┼──●│  ← 安装耳露出，孔位对齐
    │   │         │   │
    │●──┼─────────┼──●│
    └───┘         └───┘
         ↑       ↑
    螺丝固定位置
```

**步骤 3: 螺丝穿过安装耳固定到U型槽侧壁**

```
剖面图（从侧面切开）:

    U型槽侧壁        舵机安装耳
         ↓              ↓
    ┌─────────┐    ┌──┐
    │    ●────┼────┼─●│ ← M3螺丝穿过
    │    │    │    │  │
    │    │舵机│    │  │
    │    │本体│    │  │
    │    ●────┼────┼─●│
    └─────────┘    └──┘
         ↑
    螺丝孔 Φ3.2mm

固定方式:
1. M3×8mm 螺丝从外侧穿入U型槽壁
2. 穿过舵机安装耳的 Φ3mm 孔
3. 拧紧螺母（或攻丝螺纹孔）
```

---

## 🔧 为什么需要U型槽？

### 优点

| 特点 | 说明 |
|---|---|
| **三面约束** | 左、右、底三面限制舵机移动 |
| **承载能力强** | 舵机扭矩通过4个螺丝分散到支架 |
| **防止旋转** | U型槽防止舵机在负载下转动 |
| **易于组装** | 从顶部放入，无需拆卸其他部件 |
| **散热良好** | 顶部开口，利于散热 |

### 对比其他固定方式

| 方式 | 优点 | 缺点 |
|---|---|---|
| **U型槽** | 稳固、易装配 | 需要加工槽 |
| **L型支架** | 简单 | 只有两面约束，易晃动 |
| **平板+螺丝** | 最简单 | 强度差，舵机易转动 |
| **3D打印外壳** | 全包裹 | 散热差，难拆卸 |

---

## 📏 U型槽关键尺寸

### DS3218 舵机的U型槽设计参数

```
尺寸计算:
- 内宽 = 舵机宽度 + 2mm 间隙 = 20 + 2 = 22mm
- 深度 = 舵机高度 + 4mm 余量 = 41 + 4 = 45mm
- 长度 = 舵机长度 + 1.5mm 间隙 = 40.5 + 1.5 = 42mm

侧壁厚度:
- 最小: 3mm (铝合金)
- 推荐: 4-5mm (3D打印)
- 安全: 6mm (受力较大时)

螺丝孔位置:
- 距离U型槽底部: 20mm, 30mm (间距10mm)
- 孔径: Φ3.2mm (M3螺丝)
- 埋头孔: 可选，用于M3埋头螺丝
```

### 完整U型槽3D尺寸示意

```
立体图:
           26mm (外宽)
    ┌─────────────────────┐
    │  ↑                  │
    │  │ 50mm (长度)      │
    │  ↓                  │
    │  ┌──────────────┐   │  ← 顶部开口
    │  │              │   │
    │  │   U型槽内腔  │   │  ← 深度45mm
    │  │              │   │     宽度22mm
    │  └──────────────┘   │     长度42mm
    │                     │
    │  ●              ●   │  ← 安装孔位置
    │                     │
    └─────────────────────┘
           60mm (总高度)
           
关键尺寸:
- 外部尺寸: 26mm (宽) × 50mm (长) × 60mm (高)
- 内腔尺寸: 22mm (宽) × 42mm (长) × 45mm (深)
- 侧壁厚度: 2mm (左右各)
- 底部厚度: 15mm (留轴承孔空间)
```

---

## 🏗️ 实际组装过程

### 所需材料

| 材料 | 规格 | 数量（单个舵机） |
|---|---|---|
| U型支架 | 26×50×60mm | 1 个 |
| 舵机 | DS3218 | 1 个 |
| M3螺丝 | 长度8-10mm | 4 个 |
| M3螺母 | 标准 | 4 个（可选） |
| 垫片 | M3 | 4-8 个（可选） |

### 组装步骤

**1. 准备舵机和U型槽**
```
检查清单:
□ U型槽内腔无毛刺
□ 螺丝孔位置正确（间距10mm）
□ 舵机线缆整理好
```

**2. 放入舵机**
```
从U型槽顶部放入舵机
注意方向：舵机轴朝外
```

**3. 对齐孔位**
```
调整舵机位置
使安装耳上的孔与U型槽侧壁孔对齐
```

**4. 固定螺丝（重要）**
```
固定顺序（对角线原则）:
1. 先拧左上角螺丝（不要完全拧紧）
2. 再拧右下角螺丝
3. 拧左下角螺丝
4. 拧右上角螺丝
5. 按对角线顺序逐个拧紧

扭矩: 0.5-0.8 N·m (手紧 + 1/4圈)
过紧会压坏舵机外壳！
```

**5. 验证**
```
检查清单:
□ 舵机无晃动
□ 螺丝全部拧紧
□ 舵机轴可自由转动
□ 线缆未被压住
```

---

## ⚠️ 常见问题

### 问题 1: 舵机放不进U型槽
**原因**: 内腔尺寸太小或舵机尺寸超标  
**解决**: 
- 测量舵机实际尺寸
- 用锉刀或砂纸扩大内腔
- 3D打印件可重新打印

### 问题 2: 孔位对不上
**原因**: 螺丝孔位置不准确（常见于20mm间距）  
**解决**:
- 确认孔距为10mm（DS3218标准）
- 重新钻孔或修正DXF文件
- 使用本次修复后的DXF文件

### 问题 3: 螺丝拧紧后舵机卡死
**原因**: 螺丝过长，顶到舵机齿轮  
**解决**:
- 使用8mm长螺丝（不要用10mm）
- 检查螺丝是否穿透舵机安装耳
- 在螺丝和舵机间加垫片

### 问题 4: 舵机受力时支架断裂
**原因**: 侧壁太薄或材料强度不足  
**解决**:
- 3D打印：增加侧壁厚度至5-6mm
- 使用尼龙或PETG材料（比PLA强度高）
- 改用铝合金加工U型槽

---

## 🎯 设计建议

### 对于3D打印U型槽

```python
推荐参数:
- 材料: 尼龙 > PETG > PLA
- 填充: 100% (受力部件)
- 壁厚: 5-6层 (1.2-1.4mm)
- 层高: 0.15mm (精度优先)
- 支撑: 必须（内腔顶部）
```

### 对于激光切割+折弯

```
材料: 铝合金 5052-H32
厚度: 2-3mm
折弯半径: 1-2mm
优点: 强度最高
缺点: 需要折弯机或手工折弯
```

### 对于CNC加工

```
材料: 铝合金 6061-T6
整体铣削U型槽
优点: 精度最高、强度最高
缺点: 成本高（单件约￥80）
```

---

## 📸 实物参考

参考你提供的舵机图片，可以清楚看到：
1. **安装耳位置**: 舵机中部两侧伸出的金属片
2. **安装孔**: 每侧2个Φ3mm孔，间距10mm
3. **舵机本体**: 黑色塑料外壳，40.5×20×41mm

U型槽就是为了：
- **包住这个黑色本体**（三面约束）
- **螺丝穿过金属安装耳**（四点固定）
- **防止舵机在负载下转动或脱落**

---

## 📚 相关资源

- [hardware_design_calib.md](hardware_design_calib.md) - 舵机实际尺寸测量
- [generate_stl_detailed.py](generate_stl_detailed.py) - U型槽STL生成脚本（待更新）
- [body_bottom.dxf](body_bottom.dxf) - 底板舵机孔位参考

---

**文档版本**: v1.0  
**创建日期**: 2026-05-08  
**适用舵机**: DS3218MG (20KG 数字舵机)

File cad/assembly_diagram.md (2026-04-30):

# 恐龙四足机器人 - 完整组装示意图

## 整体爆炸图（Exploded View）

```
                            ╔═══════════════════════════════╗
                            ║   2S 锂电池 (7.4V 5Ah)        ║
                            ║   电源开关                     ║
                            ╚═══════════════════════════════╝
                                        │
                                        ↓
                            ┌───────────────────────┐
                            │   LM2596 降压模块 ×2   │
                            │   #1: 5V (树莓派)      │
                            │   #2: 6V (舵机)        │
                            └───────────────────────┘
                                   ↙        ↘
                            ┌─────────┐   ┌──────────────┐
                            │树莓派 3B │   │  PCA9685     │
                            │MPU6050  │   │  舵机驱动板   │
                            └─────────┘   └──────────────┘
                                             │
                                             ↓
                            ┌────────────────────────────┐
                            │   12 个 DS3218 舵机         │
                            │   (4 腿 × 3 关节/腿)        │
                            └────────────────────────────┘
```

---

## 俯视图（Top View）- 顶板布局

```
                            前方 (X+)
                               ▲
       左侧 (Y+)               │                右侧 (Y-)
           ◄───────────────────┼───────────────────►
                               │
  Y=110mm ┌──────────────────────────────────────────┐
          │ ●S3                                  ●S8 │  ← 铜柱孔 M3
          │                                          │
          │  ┌──────────┐    ┌──────────┐           │
          │  │ LM2596#1 │    │ LM2596#2 │           │
  Y=90mm  │  │  (5V)    │    │  (6V)    │           │
          │  └──────────┘    └──────────┘           │
          │                                          │
          │  ┌──────────────┐       ┌────────┐      │
  Y=65mm  │  │  树莓派 3B    │       │电池区域│      │
          │  │  (58×49mm)   │       │5000mAh │      │
          │  └──────────────┘       └────────┘      │
          │                                          │
  Y=55mm  │ ●S2                                  ●S7 │
          │                                          │
          │         ┌──────┐                         │
  Y=45mm  │         │MPU6050│ (IMU, 水平居中)         │
          │         └──────┘                         │
          │                                          │
          │  ┌───────────┐          ◉ 电源开关       │
  Y=31mm  │  │ PCA9685   │         (Φ16.5mm)        │
          │  │(舵机驱动板)│                           │
  Y=10mm  │ ●S1          ●S4                     ●S6 │
          └──────────────────────────────────────────┘
         X=0         X=100mm                   X=200mm

图例:
  ● = M3 铜柱孔 (连接上下板)
  ◉ = 开关安装孔
  □ = 元件固定区域
```

---

## 底视图（Bottom View）- 底板布局

```
                            前方 (X+)
                               ▲
  Y=110mm ┌──────────────────────────────────────────┐
          │ ●S3                                  ●S8 │
          │                                          │
          │    ◎────────┐  ┌────────◎               │
  Y=85mm  │    │左后舵机 │  │右后舵机 │               │
          │    │DS3218   │  │DS3218   │               │
          │    └─────────┘  └─────────┘               │
          │                                          │
          │         ○ 走线孔 (Φ8mm)                   │
  Y=80mm  │                                          │
          │    ┌──────────────────────┐              │
          │    │  中央走线槽 90×10mm   │              │
  Y=60mm  │    └──────────────────────┘              │
  Y=55mm  │ ●S2                                  ●S7 │
          │                                          │
          │         ○ 走线孔 (Φ8mm)                   │
  Y=30mm  │                                          │
          │                                          │
          │    ◎────────┐  ┌────────◎               │
  Y=25mm  │    │左前舵机 │  │右前舵机 │               │
          │    │DS3218   │  │DS3218   │               │
          │    └─────────┘  └─────────┘               │
  Y=10mm  │ ●S1          ●S4                     ●S6 │
          └──────────────────────────────────────────┘
         X=0         X=100mm                   X=200mm

图例:
  ● = M3 铜柱孔
  ◎ = 髋关节舵机安装区 (4×M3 螺丝 + 轴槽)
  ○ = 走线孔
```

---

## 侧视图（Side View）- 组装剖面

```
                 前方 →
    ┌───────────────────────────────────┐
    │    顶板 (3mm 亚克力)               │ ← 树莓派、电源、PCA9685
    ├───────────────────────────────────┤
    │    M3×30 铜柱 (8 个，间距 45-90mm) │
    ├───────────────────────────────────┤
    │    底板 (3mm 亚克力)               │ ← 髋关节舵机固定
    └─┬─────────────────────────────┬───┘
      │                             │
      │ ◎ 髋关节舵机 (DS3218)         │
      ↓                             ↓
    ┌───┐                         ┌───┐
    │   │ ← U型支架                │   │
    │   ├── 肩关节舵机 (DS3218)    │   │
    │   │                         │   │
    └─┬─┘                         └─┬─┘
      │                             │
      │ ← U型支架                    │
      ↓                             ↓
    ┌───┐                         ┌───┐
    │   ├── 膝关节舵机 (DS3218)    │   │
    │   │                         │   │
    └─┬─┘                         └─┬─┘
      │                             │
      ● ← 足端球体 (Φ15mm)          ●
```

---

## 单腿结构详细图（以左前腿为例）

```
                机身底板
                    │
                    ↓
        ┌───────────────────┐
        │ 髋关节舵机 (DS3218)│ ← 4×M3 螺丝固定在底板
        │  CH0: fl_hip      │    (无需 U 型支架)
        └─────────┬─────────┘
                  │ 舵机轴 (转动轴: X 轴)
                  ↓
        ┌─────────────────┐
        │  U 型支架 #1     │ ← M3 螺丝固定舵机
        │  (铝合金)        │
        └─────────┬───────┘
                  │
        ┌─────────┴─────────┐
        │ 肩关节舵机 (DS3218)│
        │  CH1: fl_shoulder │
        └─────────┬─────────┘
                  │ 舵机轴 (转动轴: Y 轴)
                  │
                  │ 上腿连杆 (100mm)
                  ↓
        ┌─────────────────┐
        │  U 型支架 #2     │
        └─────────┬───────┘
                  │
        ┌─────────┴─────────┐
        │ 膝关节舵机 (DS3218)│
        │  CH2: fl_knee     │
        └─────────┬─────────┘
                  │ 舵机轴 (转动轴: Y 轴)
                  │
                  │ 下腿连杆 (100mm)
                  ↓
                  ●  足端球体

关节运动范围:
  - 髋关节 (hip):    ±0.5 rad  (±29°)  X 轴旋转
  - 肩关节 (shoulder): ±1.57 rad (±90°)  Y 轴旋转
  - 膝关节 (knee):    -2.6~-0.1 rad (-149°~-6°) Y 轴旋转
```

---

## 舵机与 PCA9685 连接图

```
        PCA9685 舵机驱动板
    ┌─────────────────────────┐
    │ VCC ← 5V (树莓派逻辑电源) │
    │ GND ← 共地                │
    │ V+  ← 6V (舵机专用电源)    │
    │ SDA ← GPIO2 (Pin 3)      │
    │ SCL ← GPIO3 (Pin 5)      │
    ├─────────────────────────┤
    │  舵机通道 (PWM 输出):     │
    │                         │
    │  左前腿:                 │
    │   CH0 ─→ fl_hip  (髋)   │
    │   CH1 ─→ fl_shoulder(肩)│
    │   CH2 ─→ fl_knee (膝)   │
    │                         │
    │  右前腿:                 │
    │   CH3 ─→ fr_hip         │
    │   CH4 ─→ fr_shoulder    │
    │   CH5 ─→ fr_knee        │
    │                         │
    │  左后腿:                 │
    │   CH6 ─→ rl_hip         │
    │   CH7 ─→ rl_shoulder    │
    │   CH8 ─→ rl_knee        │
    │                         │
    │  右后腿:                 │
    │   CH9 ─→ rr_hip         │
    │   CH10 ─→ rr_shoulder   │
    │   CH11 ─→ rr_knee       │
    │                         │
    │  预留:                   │
    │   CH12-15 (未使用)       │
    └─────────────────────────┘

每个舵机 3 根线:
  🟤 棕色 (GND)  → PCA9685 GND
  🔴 红色 (VCC)  → PCA9685 V+ (6V)
  🟠 橙色 (信号) → PCA9685 PWM (对应通道)
```

---

## 电源分配图

```
    ┌──────────────┐
    │ 2S 锂电池     │
    │ 7.4V 5Ah     │
    │ (XT60 接口)  │
    └──────┬───────┘
           │
           ↓
    ┌──────────────┐
    │  10A 电源开关 │
    └──────┬───────┘
           │ 7.4V 主供电轨
           │
      ┌────┴──────┐
      ↓           ↓
  ┌────────┐  ┌────────┐
  │LM2596#1│  │LM2596#2│
  │ 7.4V→  │  │ 7.4V→  │
  │  5.0V  │  │  6.0V  │
  └────┬───┘  └────┬───┘
       │           │
       ↓           ↓
  ┌─────────┐  ┌──────────┐
  │树莓派 3B │  │PCA9685 V+│
  │PCA9685  │  │(舵机供电) │
  │  VCC    │  │          │
  └─────────┘  └────┬─────┘
                    │
        ┌───────────┼───────────┐
        ↓           ↓           ↓
    [DS3218]   [DS3218]   ... [DS3218]
     舵机#1     舵机#2         舵机#12
     (6V)       (6V)           (6V)

功耗估算:
  - 树莓派 3B:     ~2.5A @ 5V  = 12.5W
  - PCA9685 逻辑:  ~0.1A @ 5V  = 0.5W
  - 12 个舵机峰值: ~12A @ 6V  = 72W (堵转)
  - 12 个舵机空载: ~0.5A @ 6V = 3W
  ─────────────────────────────────
  总功耗: 约 15-90W (取决于负载)

电池续航:
  - 5000mAh @ 7.4V = 37Wh
  - 步行状态 (30W): 约 1.2 小时
  - 静态待机 (15W): 约 2.5 小时
```

---

## 机械尺寸总览

```
                   站立高度: ~250mm
                       ▲
                       │
                   ┌───┴───┐
                   │ 机身  │  60mm (高)
                   │200×110│
                   └───┬───┘
                       │
                   ┌───┴───┐
                   │上腿杆 │  100mm
                   └───┬───┘
                       │
                   ┌───┴───┐
                   │下腿杆 │  100mm
                   └───┬───┘
                       │
                       ● 足端

机身:   200mm (长) × 110mm (宽) × 60mm (高)
腿长:   上腿 100mm + 下腿 100mm = 200mm
足迹:   ~300mm (长) × 250mm (宽)
总重:   ~1.5kg
  - 机身 + 电子: 580g
  - 电池:        280g
  - 12 舵机:     720g (60g×12)
```

---

## 组装步骤总览

```
Step 1: 底板组装
  ├─ 安装 8×M3 铜柱到底板
  └─ 安装 4 个髋关节舵机 (4×M3 螺丝)

Step 2: 顶板组装
  ├─ 安装树莓派 3B (4×M2.5 铜柱)
  ├─ 安装 PCA9685 (4×M2 螺丝)
  ├─ 安装 2×LM2596 (各 4×M3 螺丝)
  ├─ 固定 MPU6050 (双面胶 + 扎带)
  └─ 安装电源开关 (Φ16.5mm 孔 + 螺母)

Step 3: 腿部组装
  ├─ 肩关节舵机 + U型支架 #1
  ├─ 膝关节舵机 + U型支架 #2
  └─ 组装 4 条完整的腿

Step 4: 合体
  ├─ 顶板对准铜柱 → 8×M3 螺母锁紧
  └─ 穿线: 舵机线经走线槽到 PCA9685

Step 5: 接线
  ├─ 电源线路 (电池 → 开关 → 降压 → 各元件)
  ├─ I2C 总线 (Pi → PCA9685, Pi → MPU6050)
  └─ 舵机信号线 (PCA9685 CH0-11 → 12 舵机)

Step 6: 固定电池
  └─ 魔术贴带 + 扎带固定电池到顶板
```

---

## 关键采购清单

| 类别 | 项目 | 规格 | 数量 | 备注 |
|---|---|---|---|---|
| **执行器** | DS3218 舵机 | 21kg·cm, 270° | 12 | 主要执行器 |
| **支架** | U型支架 | 铝合金, 40mm | 8 | **肩膝关节用** |
| **主控** | 树莓派 3B | 1GB RAM | 1 | 控制核心 |
| **驱动** | PCA9685 | 16 通道 PWM | 1 | 舵机驱动 |
| **传感器** | MPU6050 (GY-521) | 6轴 IMU | 1 | 姿态感知 |
| **电源** | 2S 锂电池 | 7.4V 5000mAh | 1 | 主电源 |
| **降压** | LM2596 模块 | DC-DC 降压 | 2 | 5V + 6V |
| **结构** | 亚克力板 | 3mm, 200×110mm | 2 | 顶板+底板 |
| **紧固** | M3×30 铜柱 | 六角 | 8 | 连接上下板 |
| **紧固** | M3 螺丝/螺母 | 各种长度 | 50+ | 通用固定 |
| **接线** | 杜邦线 | 母对母 20cm | 20 | I2C 信号 |
| **走线** | 舵机延长线 | 3 线 30cm | 12 | 舵机连线 |

---

## 技术参数总结

| 参数 | 值 |
|---|-----|
| 自由度 (DOF) | 12 (4 腿 × 3 关节) |
| 机身尺寸 | 200 × 110 × 60 mm |
| 站立高度 | ~250 mm |
| 总重量 | ~1.5 kg |
| 舵机扭矩 | 21 kg·cm @ 6V |
| 控制频率 | ~50 Hz (I2C 限制) |
| 电池容量 | 7.4V 5000mAh (37Wh) |
| 续航时间 | 1-2.5 小时 |
| 通信协议 | I2C (树莓派 ↔ 外设) |
| PWM 频率 | 50 Hz (舵机标准) |

---

## 配色方案（URDF 定义）

- 🟢 **机身 (base_link)**: 恐龙绿 `rgb(0.2, 0.6, 0.2)`
- 🟢 **上腿杆**: 恐龙绿 (同机身)
- ⚫ **髋关节/下腿杆**: 深灰 `rgb(0.3, 0.3, 0.3)`
- 🟠 **足端**: 橙色 `rgb(0.9, 0.5, 0.1)`

---

## 注意事项

1. **U型支架数量**: 只需 **8 个**（肩膝关节），髋关节直接螺丝固定
2. **杜邦线规格**: 母对母（树莓派排针 → PCA9685/MPU6050 排针）
3. **电源电压**: 
   - 树莓派: 5V (不能 6V！)
   - 舵机: 6V (不要超过 6.5V)
   - MPU6050: 3.3V (不能 5V！)
4. **舵机归中**: 组装前务必运行 `03_servo_center_all.py` 归中舵机
5. **I2C 地址**: 
   - PCA9685: 0x40
   - MPU6050: 0x68

---

**生成时间**: 2026-04-28  
**基于 URDF**: `/Users/tgut/Documents/code/dino_quadruped/urdf/dino_quadruped.urdf`  
**参考**: 接线图.md, 硬件对比.md, CAD README.md

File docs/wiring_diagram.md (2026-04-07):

# Dino Quadruped - Wiring Diagram

## Complete Wiring Schematic

```
═══════════════════════════════════════════════════════════════════
                         POWER SECTION
═══════════════════════════════════════════════════════════════════

  ┌──────────────┐    ┌──────────┐
  │  2S LiPo     │    │  10A     │
  │  7.4V 5Ah    ├──►─┤  Power   ├──►─┬───────────────────────┐
  │  XT60 plug   │    │  Switch  │    │                       │
  └──────────────┘    └──────────┘    │ 7.4V Main Rail        │
                                       │                       │
                              ┌────────┴──────┐    ┌──────────┴──────┐
                              │   LM2596 #1   │    │   LM2596 #2    │
                              │  IN: 7.4V     │    │  IN: 7.4V      │
                              │  OUT: 5.0V    │    │  OUT: 6.0V     │
                              │  (adj. trimpot)│    │  (adj. trimpot) │
                              └───────┬───────┘    └───────┬────────┘
                                      │ 5V Rail            │ 6V Servo Rail
                                      │                    │
                              ┌───────┴───────┐    ┌───────┴────────┐
                              │ To Pi + Logic │    │ To PCA9685 V+  │
                              └───────────────┘    └────────────────┘

═══════════════════════════════════════════════════════════════════
                     I2C BUS WIRING
═══════════════════════════════════════════════════════════════════

  Raspberry Pi 3B GPIO Header
  ┌─────────────────────────────────────┐
  │  Pin 1 (3.3V)  ──────► MPU6050 VCC │
  │  Pin 2 (5V)    ──────► PCA9685 VCC │
  │  Pin 3 (SDA/GPIO2) ─┬► PCA9685 SDA│
  │                      └► MPU6050 SDA│
  │  Pin 5 (SCL/GPIO3) ─┬► PCA9685 SCL│
  │                      └► MPU6050 SCL│
  │  Pin 6 (GND)   ──┬──► PCA9685 GND │
  │                   ├──► MPU6050 GND │
  │                   └──► LM2596 GND  │
  │  Pin 9 (GND)   ──────► (spare GND)│
  └─────────────────────────────────────┘

  Note: I2C bus needs 4.7kΩ pull-ups on SDA & SCL
        (PCA9685 breakout usually has them onboard)

═══════════════════════════════════════════════════════════════════
                     PCA9685 CONNECTIONS
═══════════════════════════════════════════════════════════════════

  PCA9685 Board
  ┌────────────────────────────────────────────────────────┐
  │                                                        │
  │  Power Input:                                          │
  │    VCC ◄── 5V (from LM2596 #1, logic power)           │
  │    GND ◄── Common GND                                  │
  │    V+  ◄── 6V (from LM2596 #2, servo power)           │
  │                                                        │
  │  I2C:                                                  │
  │    SDA ◄── Pi GPIO2 (Pin 3)                            │
  │    SCL ◄── Pi GPIO3 (Pin 5)                            │
  │                                                        │
  │  Servo Outputs (3-pin: GND/V+/PWM):                   │
  │  ┌─────────────────────────────────────────────┐       │
  │  │ CH0  ──► FL Hip Servo      (orange=signal)  │       │
  │  │ CH1  ──► FL Shoulder Servo                   │       │
  │  │ CH2  ──► FL Knee Servo                       │       │
  │  │ CH3  ──► FR Hip Servo                        │       │
  │  │ CH4  ──► FR Shoulder Servo                   │       │
  │  │ CH5  ──► FR Knee Servo                       │       │
  │  │ CH6  ──► RL Hip Servo                        │       │
  │  │ CH7  ──► RL Shoulder Servo                   │       │
  │  │ CH8  ──► RL Knee Servo                       │       │
  │  │ CH9  ──► RR Hip Servo                        │       │
  │  │ CH10 ──► RR Shoulder Servo                   │       │
  │  │ CH11 ──► RR Knee Servo                       │       │
  │  │ CH12 ──► (Reserved: Tail)                    │       │
  │  │ CH13 ──► (Reserved: Head tilt)               │       │
  │  │ CH14 ──► (Reserved: Head pan)                │       │
  │  │ CH15 ──► (Reserved: Jaw)                     │       │
  │  └─────────────────────────────────────────────┘       │
  └────────────────────────────────────────────────────────┘

═══════════════════════════════════════════════════════════════════
                     MPU6050 CONNECTIONS
═══════════════════════════════════════════════════════════════════

  MPU6050 (GY-521 Breakout)
  ┌────────────────────────────────────┐
  │  VCC  ◄── 3.3V (Pi Pin 1)         │
  │  GND  ◄── GND  (Pi Pin 6)         │
  │  SDA  ◄── SDA  (Pi Pin 3/GPIO2)   │
  │  SCL  ◄── SCL  (Pi Pin 5/GPIO3)   │
  │  AD0  ──► GND (address = 0x68)    │
  │  INT  ──► (optional: Pi GPIO17)   │
  │  XDA  ──► NC                       │
  │  XCL  ──► NC                       │
  └────────────────────────────────────┘

  Mounting orientation on robot body:
  ┌─────────────────────┐
  │      MPU6050         │  X-axis → Robot Forward
  │   ┌──────────┐      │  Y-axis → Robot Left
  │   │  X →     │      │  Z-axis → Robot Up
  │   │  Y ↑     │      │
  │   │  Z ⊙ (up)│      │  Mount flat on body plate,
  │   └──────────┘      │  chip side up, header toward rear
  └─────────────────────┘

═══════════════════════════════════════════════════════════════════
                     SERVO WIRING (DS3218)
═══════════════════════════════════════════════════════════════════

  Each DS3218 Servo has 3 wires:
  ┌──────────────────────────────────┐
  │  Brown  (GND)  ──► PCA9685 GND  │  (from V+ 6V rail)
  │  Red    (VCC)  ──► PCA9685 V+   │  (6V servo power)
  │  Orange (Signal)──► PCA9685 PWM │  (channel 0-11)
  └──────────────────────────────────┘

  PWM Parameters:
  - Frequency: 50Hz (20ms period)
  - Pulse range: 500μs ~ 2500μs (DS3218 for 270°)
  - Center: 1500μs = 135° (neutral)
  - Resolution: 12-bit (4096 steps)

  Angle Mapping:
  ┌──────────────────────────────────────────┐
  │  500μs  → 0°     (PCA9685 value: ~102)   │
  │  1500μs → 135°   (PCA9685 value: ~307)   │
  │  2500μs → 270°   (PCA9685 value: ~512)   │
  │                                           │
  │  Radians: angle_rad = (pwm_μs - 500)      │
  │           × (270°/2000μs) × (π/180°)      │
  └──────────────────────────────────────────┘

═══════════════════════════════════════════════════════════════════
                     PHYSICAL LAYOUT (Top View)
═══════════════════════════════════════════════════════════════════

                        FRONT (head)
                          ▲
           FL             │              FR
     ┌──S0──S1──S2──┐    │    ┌──S3──S4──S5──┐
     │  hip  shl knee│    │    │  hip  shl knee│
     └───────────────┘    │    └───────────────┘
                          │
    ┌─────────────────────┼─────────────────────┐
    │                     │                     │
    │  ┌─────┐  ┌───────┐│  ┌──────┐           │
    │  │ Pi  │  │PCA9685││  │MPU6050│          │
    │  │ 3B  │  │       ││  └──────┘           │
    │  └─────┘  └───────┘│                     │
    │                     │  ┌───────────┐      │
    │  ┌────────┐        │  │  Battery   │      │
    │  │LM2596×2│        │  │  2S LiPo   │      │
    │  └────────┘        │  └───────────┘      │
    │                     │        ┌──┐         │
    │                     │        │SW│ (switch) │
    └─────────────────────┼─────────────────────┘
                          │
     ┌──S6──S7──S8──┐    │    ┌──S9──S10─S11─┐
     │  hip  shl knee│    │    │  hip  shl knee│
     └───────────────┘    │    └───────────────┘
           RL             │              RR
                          ▼
                        REAR (tail)

  Component Placement Notes:
  - Pi 3B: center-left, USB ports facing left for access
  - PCA9685: center, close to all servo extension cables
  - MPU6050: center of body (center of mass), flat mount
  - Battery: center-right (heaviest, keep near CoM)
  - LM2596 modules: stacked or side-by-side near battery
  - Power switch: rear edge, easy access

  Weight Distribution Target:
  - Body + electronics: ~300g (center)
  - Battery: ~280g (center-right)
  - 12 servos × 60g: ~720g (distributed at legs)
  - Total: ~1.5kg (matches URDF mass=1.5)

═══════════════════════════════════════════════════════════════════
                     WIRE ROUTING
═══════════════════════════════════════════════════════════════════

  Servo Extension Cables (30cm each):
  - Route along body underside in cable channels
  - Bundle per leg (3 wires × 4 legs = 12 cables)
  - Use zip ties every 3cm to prevent snagging

  Power Cables (14AWG silicone):
  - Battery → Switch: 10cm, red+black
  - Switch → LM2596 #1: 8cm
  - Switch → LM2596 #2: 8cm
  - LM2596 #2 → PCA9685 V+: 5cm (keep short for current)

  I2C Cables (dupont wires):
  - Pi → PCA9685: 8cm (4 wires: VCC/GND/SDA/SCL)
  - Pi → MPU6050: 6cm (4 wires: VCC/GND/SDA/SCL)
  - Keep I2C wires away from servo power lines (EMI)

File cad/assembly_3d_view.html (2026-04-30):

# 🦖 恐龙四足机器人

基于真实采购器件的 3D 组装可视化

### 📐 视角控制

重置视角 俯视图 侧视图 正视图

### 🔍 显示选项

机身板 舵机 (12个) 电子元件 腿部结构

### 🎨 渲染模式

实体模式 线框模式 透视模式

### ⚡ 动画

自动旋转 行走动画 爆炸视图

机身板 (200×110mm)

DS3218 舵机 (12个)

U型支架 (8个)

树莓派 3B

PCA9685

锂电池

### 📋 技术规格

#### 🔧 执行器

12 × DS3218 舵机
扭矩: 21 kg·cm
转角: 270°
尺寸: 40.7×20.2×36.2 mm

#### 🦾 U型支架

8 个铝合金支架
肩关节: 4 个
膝关节: 4 个
髋关节: 直接固定（无需支架）

#### 💻 主控系统

树莓派 3B
尺寸: 85.6×56 mm
PCA9685 舵机驱动
MPU6050 IMU 传感器

#### ⚡ 电源系统

2S 锂电池 7.4V 5Ah
LM2596 #1: 5V (树莓派)
LM2596 #2: 6V (舵机)
续航: 1-2.5 小时

#### 📏 机械尺寸

机身: 200×110×60 mm
站立高度: ~250 mm
腿长: 200 mm (上腿+下腿)
总重: ~1.5 kg

#### 🎯 自由度

12 DOF
每腿 3 个关节:
• 髋关节 (Hip Yaw)
• 肩关节 (Shoulder Pitch)
• 膝关节 (Knee Pitch)

💡 提示: 拖动鼠标旋转视角 | 滚轮缩放 | 右键平移

📁 组装图生成时间: 2026-04-28

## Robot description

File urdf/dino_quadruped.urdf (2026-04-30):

<?xml version="1.0" ?>
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
<robot name="dino_quadruped">

  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
  <link name="base_link">
    <inertial>
      <origin xyz="0 0 0" rpy="0 0 0"/>
      <mass value="1.5"/>
      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
    </inertial>
    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
  </link>

  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
  <link name="fl_hip">
    <inertial>
      <origin xyz="0 0.02 0" rpy="0 0 0"/>
      <mass value="0.1"/>
      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
    </inertial>
    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
  </link>

  <joint name="fl_hip_joint" type="revolute">
    <parent link="base_link"/>
    <child link="fl_hip"/>
    <origin xyz="0.08 0.055 0" rpy="0 0 0"/>
    <axis xyz="1 0 0"/>
    <limit lower="-0.5" upper="0.5" effort="10" velocity="5"/>
  </joint>

  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
  <link name="fl_hip_bracket">
    <inertial>
      <origin xyz="0 0.02 -0.01" rpy="0 0 0"/>
      <mass value="0.05"/>
      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
    </inertial>
    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
  </link>

  <joint name="fl_hip_bracket_joint" type="fixed">
    <parent link="fl_hip"/>
    <child link="fl_hip_bracket"/>
    <origin xyz="0 0 0" rpy="0 0 0"/>
  </joint>

  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
  <link name="fl_upper_leg">
    <inertial>
      <origin xyz="0 0 -0.05" rpy="0 0 0"/>
      <mass value="0.15"/>
      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
    </inertial>
    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
  </link>

  <joint name="fl_shoulder_joint" type="revolute">
    <parent link="fl_hip"/>
    <child link="fl_upper_leg"/>
    <origin xyz="0 0.04 0" rpy="0 0 0"/>
    <axis xyz="0 1 0"/>
    <limit lower="-1.57" upper="1.57" effort="10" velocity="5"/>
  </joint>

  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
  <link name="fl_lower_leg">
    <inertial>
      <origin xyz="0 0 -0.05" rpy="0 0 0"/>
      <mass value="0.1"/>
      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
    </inertial>
    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
  </link>

  <joint name="fl_knee_joint" type="revolute">
    <parent link="fl_upper_leg"/>
    <child link="fl_lower_leg"/>
    <origin xyz="0 0 -0.10" rpy="0 0 0"/>
    <axis xyz="0 1 0"/>
    <limit lower="-2.6" upper="-0.1" effort="10" velocity="5"/>
  </joint>

  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
  <link name="fl_knee_bracket">
    <inertial>
      <origin xyz="0 0 -0.01" rpy="0 0 0"/>
      <mass value="0.03"/>
      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
    </inertial>
    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
  </link>

  <joint name="fl_knee_bracket_joint" type="fixed">
    <parent link="fl_upper_leg"/>
    <child link="fl_knee_bracket"/>
    <origin xyz="0 0 -0.10" rpy="0 0 0"/>
  </joint>

  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
  <link name="fl_foot">
    <inertial>
      <origin xyz="0 0 0" rpy="0 0 0"/>
      <mass value="0.02"/>
      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
    </inertial>
    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
  </link>

  <joint name="fl_foot_joint" type="fixed">
    <parent link="fl_lower_leg"/>
    <child link="fl_foot"/>
    <origin xyz="0 0 -0.10" rpy="0 0 0"/>
  </joint>

  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
  <link name="fr_hip">
    <inertial>
      <origin xyz="0 -0.02 0" rpy="0 0 0"/>
      <mass value="0.1"/>
      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
    </inertial>
    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
  </link>

  <joint name="fr_hip_joint" type="revolute">
    <parent link="base_link"/>
    <child link="fr_hip"/>
    <origin xyz="0.08 -0.055 0" rpy="0 0 0"/>
    <axis xyz="1 0 0"/>
    <limit lower="-0.5" upper="0.5" effort="10" velocity="5"/>
  </joint>

  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
  <link name="fr_hip_bracket">
    <inertial>
      <origin xyz="0 -0.02 -0.01" rpy="0 0 0"/>
      <mass value="0.05"/>
      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
    </inertial>
    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
  </link>

  <joint name="fr_hip_bracket_joint" type="fixed">
    <parent link="fr_hip"/>
    <child link="fr_hip_bracket"/>
    <origin xyz="0 0 0" rpy="0 0 0"/>
  </joint>

  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
  <link name="fr_upper_leg">
    <inertial>
      <origin xyz="0 0 -0.05" rpy="0 0 0"/>
      <mass value="0.15"/>
      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
    </inertial>
    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
  </link>

  <joint name="fr_shoulder_joint" type="revolute">
    <parent link="fr_hip"/>
    <child link="fr_upper_leg"/>
    <origin xyz="0 -0.04 0" rpy="0 0 0"/>
    <axis xyz="0 1 0"/>
    <limit lower="-1.57" upper="1.57" effort="10" velocity="5"/>
  </joint>

  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
  <link name="fr_lower_leg">
    <inertial>
      <origin xyz="0 0 -0.05" rpy="0 0 0"/>
      <mass value="0.1"/>
      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
    </inertial>
    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
  </link>

  <joint name="fr_knee_joint" type="revolute">
    <parent link="fr_upper_leg"/>
    <child link="fr_lower_leg"/>
    <origin xyz="0 0 -0.10" rpy="0 0 0"/>
    <axis xyz="0 1 0"/>
    <limit lower="-2.6" upper="-0.1" effort="10" velocity="5"/>
  </joint>

  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
  <link name="fr_knee_bracket">
    <inertial>
      <origin xyz="0 0 -0.01" rpy="0 0 0"/>
      <mass value="0.03"/>
      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
    </inertial>
    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
  </link>

  <joint name="fr_knee_bracket_joint" type="fixed">
    <parent link="fr_upper_leg"/>
    <child link="fr_knee_bracket"/>
    <origin xyz="0 0 -0.10" rpy="0 0 0"/>
  </joint>

  <link name="fr_foot">
    <inertial>
      <origin xyz="0 0 0" rpy="0 0 0"/>
      <mass value="0.02"/>
      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
    </inertial>
    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
  </link>

  <joint name="fr_foot_joint" type="fixed">
    <parent link="fr_lower_leg"/>
    <child link="fr_foot"/>
    <origin xyz="0 0 -0.10" rpy="0 0 0"/>
  </joint>

  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
  <link name="rl_hip">
    <inertial>
      <origin xyz="0 0.02 0" rpy="0 0 0"/>
      <mass value="0.1"/>
      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
    </inertial>
    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
  </link>

  <joint name="rl_hip_joint" type="revolute">
    <parent link="base_link"/>
    <child link="rl_hip"/>
    <origin xyz="-0.08 0.055 0" rpy="0 0 0"/>
    <axis xyz="1 0 0"/>
    <limit lower="-0.5" upper="0.5" effort="10" velocity="5"/>
  </joint>

  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
  <link name="rl_hip_bracket">
    <inertial>
      <origin xyz="0 0.02 -0.01" rpy="0 0 0"/>
      <mass value="0.05"/>
      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
    </inertial>
    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
  </link>

  <joint name="rl_hip_bracket_joint" type="fixed">
    <parent link="rl_hip"/>
    <child link="rl_hip_bracket"/>
    <origin xyz="0 0 0" rpy="0 0 0"/>
  </joint>

  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
  <link name="rl_upper_leg">
    <inertial>
      <origin xyz="0 0 -0.05" rpy="0 0 0"/>
      <mass value="0.15"/>
      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
    </inertial>
    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
  </link>

  <joint name="rl_shoulder_joint" type="revolute">
    <parent link="rl_hip"/>
    <child link="rl_upper_leg"/>
    <origin xyz="0 0.04 0" rpy="0 0 0"/>
    <axis xyz="0 1 0"/>
    <limit lower="-1.57" upper="1.57" effort="10" velocity="5"/>
  </joint>

  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
  <link name="rl_lower_leg">
    <inertial>
      <origin xyz="0 0 -0.05" rpy="0 0 0"/>
      <mass value="0.1"/>
      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
    </inertial>
    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
  </link>

  <joint name="rl_knee_joint" type="revolute">
    <parent link="rl_upper_leg"/>
    <child link="rl_lower_leg"/>
    <origin xyz="0 0 -0.10" rpy="0 0 0"/>
    <axis xyz="0 1 0"/>
    <limit lower="-2.6" upper="-0.1" effort="10" velocity="5"/>
  </joint>

  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
  <link name="rl_knee_bracket">
    <inertial>
      <origin xyz="0 0 -0.01" rpy="0 0 0"/>
      <mass value="0.03"/>
      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
    </inertial>
    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
  </link>

  <joint name="rl_knee_bracket_joint" type="fixed">
    <parent link="rl_upper_leg"/>
    <child link="rl_knee_bracket"/>
    <origin xyz="0 0 -0.10" rpy="0 0 0"/>
  </joint>

  <link name="rl_foot">
    <inertial>
      <origin xyz="0 0 0" rpy="0 0 0"/>
      <mass value="0.02"/>
      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
    </inertial>
    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
  </link>

  <joint name="rl_foot_joint" type="fixed">
    <parent link="rl_lower_leg"/>
    <child link="rl_foot"/>
    <origin xyz="0 0 -0.10" rpy="0 0 0"/>
  </joint>

  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
  <link name="rr_hip">
    <inertial>
      <origin xyz="0 -0.02 0" rpy="0 0 0"/>
      <mass value="0.1"/>
      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
    </inertial>
    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
  </link>

  <joint name="rr_hip_joint" type="revolute">
    <parent link="base_link"/>
    <child link="rr_hip"/>
    <origin xyz="-0.08 -0.055 0" rpy="0 0 0"/>
    <axis xyz="1 0 0"/>
    <limit lower="-0.5" upper="0.5" effort="10" velocity="5"/>
  </joint>

  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
  <link name="rr_hip_bracket">
    <inertial>
      <origin xyz="0 -0.02 -0.01" rpy="0 0 0"/>
      <mass value="0.05"/>
      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
    </inertial>
    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
  </link>

  <joint name="rr_hip_bracket_joint" type="fixed">
    <parent link="rr_hip"/>
    <child link="rr_hip_bracket"/>
    <origin xyz="0 0 0" rpy="0 0 0"/>
  </joint>

  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
  <link name="rr_upper_leg">
    <inertial>
      <origin xyz="0 0 -0.05" rpy="0 0 0"/>
      <mass value="0.15"/>
      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
    </inertial>
    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
  </link>

  <joint name="rr_shoulder_joint" type="revolute">
    <parent link="rr_hip"/>
    <child link="rr_upper_leg"/>
    <origin xyz="0 -0.04 0" rpy="0 0 0"/>
    <axis xyz="0 1 0"/>
    <limit lower="-1.57" upper="1.57" effort="10" velocity="5"/>
  </joint>
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

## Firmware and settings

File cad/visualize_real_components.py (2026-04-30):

#!/usr/bin/env python3
"""
Dino Quadruped 真实器件 3D 组装可视化
基于实际采购的器件尺寸绘制 3D 组装效果图

运行方式：
    python3 cad/visualize_real_components.py

需要：matplotlib (通常已安装)
"""

import matplotlib.pyplot as plt
from mpl_toolkits.mplot3d import Axes3D
from mpl_toolkits.mplot3d.art3d import Poly3DCollection
import numpy as np

class RealComponentVisualizer:
    """真实器件 3D 可视化器"""

    def __init__(self):
        self.fig = plt.figure(figsize=(16, 12))
        self.ax = self.fig.add_subplot(111, projection='3d')

        # 设置坐标轴
        self.ax.set_xlabel('X (mm) - 前后', fontsize=12)
        self.ax.set_ylabel('Y (mm) - 左右', fontsize=12)
        self.ax.set_zlabel('Z (mm) - 高度', fontsize=12)

        # 设置视角
        self.ax.view_init(elev=20, azim=45)

    def draw_box(self, center, size, color, alpha=0.7, label=None):
        """绘制长方体"""
        x, y, z = center
        dx, dy, dz = size

        # 定义 8 个顶点
        vertices = np.array([
            [x-dx/2, y-dy/2, z-dz/2],
            [x+dx/2, y-dy/2, z-dz/2],
            [x+dx/2, y+dy/2, z-dz/2],
            [x-dx/2, y+dy/2, z-dz/2],
            [x-dx/2, y-dy/2, z+dz/2],
            [x+dx/2, y-dy/2, z+dz/2],
            [x+dx/2, y+dy/2, z+dz/2],
            [x-dx/2, y+dy/2, z+dz/2],
        ])

        # 定义 6 个面
        faces = [
            [vertices[0], vertices[1], vertices[5], vertices[4]],  # 前
            [vertices[2], vertices[3], vertices[7], vertices[6]],  # 后
            [vertices[0], vertices[3], vertices[7], vertices[4]],  # 左
            [vertices[1], vertices[2], vertices[6], vertices[5]],  # 右
            [vertices[0], vertices[1], vertices[2], vertices[3]],  # 下
            [vertices[4], vertices[5], vertices[6], vertices[7]],  # 上
        ]

        poly = Poly3DCollection(faces, alpha=alpha, facecolor=color, edgecolor='black', linewidth=0.5)
        self.ax.add_collection3d(poly)

        # 添加标签
        if label:
            self.ax.text(x, y, z+dz/2+5, label, fontsize=9, ha='center',
                        bbox=dict(boxstyle='round,pad=0.3', facecolor='white', alpha=0.8))

    def draw_cylinder(self, center, radius, height, color, alpha=0.7, label=None):
        """绘制圆柱体（用于舵机）"""
        x, y, z = center

        # 生成圆柱面
        theta = np.linspace(0, 2*np.pi, 20)
        z_line = np.linspace(z-height/2, z+height/2, 2)

        X = x + radius * np.outer(np.cos(theta), np.ones(len(z_line)))
        Y = y + radius * np.outer(np.sin(theta), np.ones(len(z_line)))
        Z = np.outer(np.ones(len(theta)), z_line)

        self.ax.plot_surface(X, Y, Z, color=color, alpha=alpha)

        # 顶部和底部圆
        for z_cap in [z-height/2, z+height/2]:
            x_cap = x + radius * np.cos(theta)
            y_cap = y + radius * np.sin(theta)
            z_cap_arr = np.full_like(theta, z_cap)

            verts = [list(zip(x_cap, y_cap, z_cap_arr))]
            poly = Poly3DCollection(verts, alpha=alpha, facecolor=color, edgecolor='black', linewidth=0.5)
            self.ax.add_collection3d(poly)

        if label:
            self.ax.text(x, y, z+height/2+3, label, fontsize=7, ha='center')

    def draw_servo(self, position, rotation_axis='z', label=''):
        """绘制 DS3218 舵机（真实尺寸）"""
        x, y, z = position

        # DS3218 尺寸: 40.7 × 20.2 × 36.2 mm
        servo_length = 40.7
        servo_width = 20.2
        servo_height = 36.2

        if rotation_axis == 'x':
            size = (servo_height, servo_width, servo_length)
        elif rotation_axis == 'y':
            size = (servo_length, servo_height, servo_width)
        else:  # z
            size = (servo_length, servo_width, servo_height)

        self.draw_box((x, y, z), size, color='#2C3E50', alpha=0.8, label=label)

        # 舵机轴（小圆柱）
        if rotation_axis == 'z':
            self.draw_cylinder((x, y, z+servo_height/2+3), 3, 6, color='white', alpha=1.0)

    def draw_u_bracket(self, position, label=''):
        """绘制 U 型支架"""
        x, y, z = position

        # U 型支架简化为框架
        bracket_width = 42  # 内宽
        bracket_height = 50
        bracket_thickness = 3

        # 左侧板
        self.draw_box((x-bracket_width/2, y, z),
                     (bracket_thickness, 20, bracket_height),
                     color='silver', alpha=0.6)

        # 右侧板
        self.draw_box((x+bracket_width/2, y, z),
                     (bracket_thickness, 20, bracket_height),
                     color='silver', alpha=0.6)

        if label:
            self.ax.text(x, y, z+bracket_height/2+3, label, fontsize=7, ha='center', color='gray')

    def visualize_assembly(self):
        """绘制完整组装图"""

        # ==================== 机身板 ====================
        body_length = 200
        body_width = 110
        body_height = 3  # 亚克力板厚度

        # 底板
        self.draw_box((0, 0, 0), (body_length, body_width, body_height),
                     color='lightblue', alpha=0.3, label='底板 (200×110×3mm)')

        # 顶板（通过铜柱抬高 30mm）
        top_plate_z = 30
        self.draw_box((0, 0, top_plate_z), (body_length, body_width, body_height),
                     color='lightblue', alpha=0.3, label='顶板')

        # 铜柱（8 个 M3×30）
        standoff_positions = [
            (-90, -45, 15), (-90, 0, 15), (-90, 45, 15),
            (0, -45, 15),
            (80, -45, 15), (80, 0, 15), (80, 45, 15),
            (0, 45, 15),
        ]
        for i, pos in enumerate(standoff_positions):
            self.draw_cylinder(pos, 3, 30, color='gold', alpha=0.9)

        # ==================== 顶板元件 ====================
        component_z = top_plate_z + body_height + 2

        # 1. 树莓派 3B (85.6 × 56 × 17 mm)
        rpi_x = -40
        rpi_y = 10
        self.draw_box((rpi_x, rpi_y, component_z + 8.5),
                     (85.6, 56, 17),
                     color='green', alpha=0.8, label='树莓派 3B\n85.6×56mm')

        # 2. PCA9685 (25 × 61 × 8 mm)
        pca_x = -40
        pca_y = -30
        self.draw_box((pca_x, pca_y, component_z + 4),
                     (61, 25, 8),
                     color='blue', alpha=0.8, label='PCA9685\n舵机驱动板')

        # 3. MPU6050 (GY-521, 15 × 20 × 3 mm)
        mpu_x = 5
        mpu_y = 0
        self.draw_box((mpu_x, mpu_y, component_z + 1.5),
                     (20, 15, 3),
                     color='purple', alpha=0.8, label='MPU6050\nIMU')

        # 4. LM2596 降压模块 ×2 (37 × 15 × 14 mm)
        lm1_x = 50
        lm1_y = 35
        self.draw_box((lm1_x, lm1_y, component_z + 7),
                     (37, 15, 14),
                     color='red', alpha=0.8, label='LM2596 #1\n(5V)')

        lm2_x = 50
        lm2_y = 8
        self.draw_box((lm2_x, lm2_y, component_z + 7),
                     (37, 15, 14),
                     color='red', alpha=0.8, label='LM2596 #2\n(6V)')

        # 5. 电池 (150 × 50 × 30 mm)
        battery_x = 50
        battery_y = -25
        self.draw_box((battery_x, battery_y, component_z + 15),
                     (70, 50, 30),
                     color='orange', alpha=0.7, label='2S 锂电池\n7.4V 5Ah')

        # 6. 电源开关（圆形，简化为小圆柱）
        switch_x = 30
        switch_y = -45
        self.draw_cylinder((switch_x, switch_y, component_z), 8, 10,
                          color='red', alpha=1.0, label='电源开关')

        # ==================== 髋关节舵机（底板固定）====================
        hip_servo_z = body_height + 18  # 舵机中心高度

        # 左前髋
        self.draw_servo((70, 45, hip_servo_z), rotation_axis='x',
                       label='左前髋\nCH0')

        # 右前髋
        self.draw_servo((70, -45, hip_servo_z), rotation_axis='x',
                       label='右前髋\nCH3')

        # 左后髋
        self.draw_servo((-70, 45, hip_servo_z), rotation_axis='x',
                       label='左后髋\nCH6')

        # 右后髋
        self.draw_servo((-70, -45, hip_servo_z), rotation_axis='x',
                       label='右后髋\nCH9')

        # ==================== 腿部结构（以左前腿为例）====================
        leg_start_z = hip_servo_z - 18

        # 左前腿
        fl_x, fl_y = 70, 45

        # U型支架 #1（肩关节）
        shoulder_z = leg_start_z - 25
        self.draw_u_bracket((fl_x, fl_y + 30, shoulder_z), label='U型支架')

        # 肩关节舵机
        self.draw_servo((fl_x, fl_y + 30, shoulder_z), rotation_axis='y',
                       label='左前肩\nCH1')

        # 上腿杆（100mm，简化为长方体）
        upper_leg_z = shoulder_z - 50
        self.draw_box((fl_x, fl_y + 30, upper_leg_z),
                     (10, 10, 100),
                     color='lightgreen', alpha=0.6, label='上腿杆\n100mm')

        # U型支架 #2（膝关节）
        knee_z = shoulder_z - 100
        self.draw_u_bracket((fl_x, fl_y + 30, knee_z), label='U型支架')

        # 膝关节舵机
        self.draw_servo((fl_x, fl_y + 30, knee_z), rotation_axis='y',
                       label='左前膝\nCH2')

        # 下腿杆（100mm）
        lower_leg_z = knee_z - 50
        self.draw_box((fl_x, fl_y + 30, lower_leg_z),
                     (8, 8, 100),
                     color='darkgreen', alpha=0.6, label='下腿杆\n100mm')

        # 足端球体
        foot_z = knee_z - 100
        self.draw_cylinder((fl_x, fl_y + 30, foot_z), 7, 14,
                          color='orange', alpha=1.0, label='足端')

        # ==================== 其他三条腿（简化绘制）====================
        # 右前腿
        fr_x, fr_y = 70, -45
        self.draw_u_bracket((fr_x, fr_y - 30, shoulder_z), label='')
        self.draw_servo((fr_x, fr_y - 30, shoulder_z), rotation_axis='y', label='右前肩\nCH4')
        self.draw_box((fr_x, fr_y - 30, upper_leg_z), (10, 10, 100), color='lightgreen', alpha=0.4)
        self.draw_u_bracket((fr_x, fr_y - 30, knee_z), label='')
        self.draw_servo((fr_x, fr_y - 30, knee_z), rotation_axis='y', label='右前膝\nCH5')
        self.draw_box((fr_x, fr_y - 30, lower_leg_z), (8, 8, 100), color='darkgreen', alpha=0.4)
        self.draw_cylinder((fr_x, fr_y - 30, foot_z), 7, 14, color='orange', alpha=1.0)

        # 左后腿
        rl_x, rl_y = -70, 45
        self.draw_u_bracket((rl_x, rl_y + 30, shoulder_z), label='')
        self.draw_servo((rl_x, rl_y + 30, shoulder_z), rotation_axis='y', label='左后肩\nCH7')
        self.draw_box((rl_x, rl_y + 30, upper_leg_z), (10, 10, 100), color='lightgreen', alpha=0.4)
        self.draw_u_bracket((rl_x, rl_y + 30, knee_z), label='')
        self.draw_servo((rl_x, rl_y + 30, knee_z), rotation_axis='y', label='左后膝\nCH8')
        self.draw_box((rl_x, rl_y + 30, lower_leg_z), (8, 8, 100), color='darkgreen', alpha=0.4)
        self.draw_cylinder((rl_x, rl_y + 30, foot_z), 7, 14, color='orange', alpha=1.0)

        # 右后腿
        rr_x, rr_y = -70, -45
        self.draw_u_bracket((rr_x, rr_y - 30, shoulder_z), label='')
        self.draw_servo((rr_x, rr_y - 30, shoulder_z), rotation_axis='y', label='右后肩\nCH10')
        self.draw_box((rr_x, rr_y - 30, upper_leg_z), (10, 10, 100), color='lightgreen', alpha=0.4)
        self.draw_u_bracket((rr_x, rr_y - 30, knee_z), label='')
        self.draw_servo((rr_x, rr_y - 30, knee_z), rotation_axis='y', label='右后膝\nCH11')
        self.draw_box((rr_x, rr_y - 30, lower_leg_z), (8, 8, 100), color='darkgreen', alpha=0.4)
        self.draw_cylinder((rr_x, rr_y - 30, foot_z), 7, 14, color='orange', alpha=1.0)

        # ==================== 地面参考线 ====================
        ground_z = foot_z - 10
        xx, yy = np.meshgrid(np.linspace(-120, 120, 2), np.linspace(-80, 80, 2))
        zz = np.full_like(xx, ground_z)
        self.ax.plot_surface(xx, yy, zz, alpha=0.1, color='gray')

        # ==================== 设置显示范围 ====================
        self.ax.set_xlim([-120, 120])
        self.ax.set_ylim([-80, 80])
        self.ax.set_zlim([ground_z, component_z + 60])

        # 添加标题
        self.ax.set_title('恐龙四足机器人 - 真实器件 3D 组装图\n' +
                         '基于实际采购的 DS3218 舵机和电子元件',
                         fontsize=14, fontweight='bold', pad=20)

        # 添加图例
        from matplotlib.patches import Patch
        legend_elements = [
            Patch(facecolor='lightblue', alpha=0.3, label='机身板 (亚克力 3mm)'),
            Patch(facecolor='#2C3E50', alpha=0.8, label='DS3218 舵机 (12个)'),
            Patch(facecolor='silver', alpha=0.6, label='U型支架 (8个)'),
            Patch(facecolor='green', alpha=0.8, label='树莓派 3B'),
            Patch(facecolor='blue', alpha=0.8, label='PCA9685 驱动板'),
            Patch(facecolor='orange', alpha=0.7, label='2S 锂电池'),
            Patch(facecolor='lightgreen', alpha=0.6, label='腿部连杆'),
        ]
        self.ax.legend(handles=legend_elements, loc='upper left', fontsize=10)

        # 添加信息文本
        info_text = (
            '总重: ~1.5kg\n'
            '机身: 200×110×60mm\n'
            '舵机: DS3218 × 12\n'
            'U型支架: 8个\n'
            '站立高度: ~250mm'
        )
        self.ax.text2D(0.02, 0.98, info_text, transform=self.ax.transAxes,
                      fontsize=10, verticalalignment='top',
                      bbox=dict(boxstyle='round', facecolor='wheat', alpha=0.8))

        # 网格
        self.ax.grid(True, alpha=0.3)

    def show(self):
        """显示图形"""
        plt.tight_layout()

        # 添加交互提示
        print("\n" + "="*60)
        print("  恐龙四足机器人 - 真实器件 3D 可视化")
        print("="*60)
        print("\n交互操作:")
        print("  - 鼠标左键拖动: 旋转视角")
        print("  - 鼠标右键拖动: 平移")
        print("  - 鼠标滚轮: 缩放")
        print("  - 工具栏保存按钮: 保存为图片")
        print("\n关闭窗口退出")
        print("="*60 + "\n")

        plt.show()


def main():
    """主函数"""
    visualizer = RealComponentVisualizer()
    visualizer.visualize_assembly()
    visualizer.show()


if __name__ == '__main__':
    main()

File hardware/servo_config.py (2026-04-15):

"""
舵机配置 - 通道映射与 PWM 参数
所有硬件脚本共用此配置。
"""

# PCA9685 I2C 地址
PCA9685_ADDR = 0x40

# PWM 频率 (Hz)
PWM_FREQ = 50

# DS3218 舵机 PWM 参数 (微秒)
SERVO_MIN_US = 500    # 0°
SERVO_MID_US = 1500   # 135° (归中)
SERVO_MAX_US = 2500   # 270°
SERVO_RANGE_DEG = 270  # 总行程角度

# PCA9685 12-bit (4096) 值换算
# pulse_us -> pca_value = (pulse_us / 20000) * 4096
SERVO_MIN_VAL = 102   # 500μs
SERVO_MID_VAL = 307   # 1500μs
SERVO_MAX_VAL = 512   # 2500μs

# 舵机通道映射 (与接线图一致)
CHANNEL_MAP = {
    # 左前腿
    "fl_hip":      0,
    "fl_shoulder": 1,
    "fl_knee":     2,
    # 右前腿
    "fr_hip":      3,
    "fr_shoulder": 4,
    "fr_knee":     5,
    # 左后腿
    "rl_hip":      6,
    "rl_shoulder": 7,
    "rl_knee":     8,
    # 右后腿
    "rr_hip":      9,
    "rr_shoulder": 10,
    "rr_knee":     11,
}

# 按腿分组
LEG_CHANNELS = {
    "fl": ["fl_hip", "fl_shoulder", "fl_knee"],
    "fr": ["fr_hip", "fr_shoulder", "fr_knee"],
    "rl": ["rl_hip", "rl_shoulder", "rl_knee"],
    "rr": ["rr_hip", "rr_shoulder", "rr_knee"],
}

# 舵机安装方向修正 (1=正向, -1=镜像)
# 右侧腿的肩/膝舵机通常需要反向
SERVO_DIRECTION = {
    "fl_hip": 1,  "fl_shoulder": 1,  "fl_knee": 1,
    "fr_hip": -1, "fr_shoulder": -1, "fr_knee": -1,
    "rl_hip": 1,  "rl_shoulder": 1,  "rl_knee": 1,
    "rr_hip": -1, "rr_shoulder": -1, "rr_knee": -1,
}

# 舵机校准偏移量 (微秒) - 组装后根据实际情况调整
# 理想情况下所有为 0，实际需要微调
SERVO_OFFSET_US = {name: 0 for name in CHANNEL_MAP}


def us_to_pca(pulse_us):
    """微秒脉宽 -> PCA9685 12-bit 值"""
    return int((pulse_us / 20000.0) * 4096)


def angle_to_us(angle_deg):
    """角度(0-270) -> 微秒脉宽"""
    return SERVO_MIN_US + (angle_deg / SERVO_RANGE_DEG) * (SERVO_MAX_US - SERVO_MIN_US)


def rad_to_us(angle_rad, joint_name):
    """
    弧度 -> 微秒脉宽 (带方向修正和偏移校准)
    仿真中 0 rad = 归中位置
    """
    import math
    direction = SERVO_DIRECTION.get(joint_name, 1)
    offset = SERVO_OFFSET_US.get(joint_name, 0)
    angle_deg = math.degrees(angle_rad) * direction
    pulse_us = SERVO_MID_US + (angle_deg / SERVO_RANGE_DEG) * (SERVO_MAX_US - SERVO_MIN_US) + offset
    return max(SERVO_MIN_US, min(SERVO_MAX_US, pulse_us))

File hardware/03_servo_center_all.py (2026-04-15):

#!/usr/bin/env python3
"""
Step 3: 全部舵机归中
组装前必做！先把所有舵机转到中位，再安装舵机角/连杆。
这样保证机械零位 = 电气零位。

用法:
    python3 03_servo_center_all.py           # 所有12个舵机归中
    python3 03_servo_center_all.py --leg fl  # 只归中左前腿
"""

import argparse
import time
import sys

try:
    from adafruit_servokit import ServoKit
except ImportError:
    print("[ERROR] 需要安装: pip3 install adafruit-circuitpython-servokit")
    sys.exit(1)

from servo_config import (
    CHANNEL_MAP, LEG_CHANNELS, SERVO_RANGE_DEG,
    SERVO_MIN_US, SERVO_MAX_US
)


def main():
    parser = argparse.ArgumentParser(description="舵机全部归中")
    parser.add_argument("--leg", choices=["fl", "fr", "rl", "rr"],
                        help="只归中指定腿")
    args = parser.parse_args()

    print("=" * 50)
    print("  Dino Quadruped - 舵机归中")
    print("=" * 50)
    print()
    print("  [重要] 此脚本将所有舵机转到 135°(中位)")
    print("  请确保腿部连杆尚未锁死，或已断开舵机角")
    print()

    kit = ServoKit(channels=16)
    for ch in range(16):
        kit.servo[ch].set_pulse_width_range(SERVO_MIN_US, SERVO_MAX_US)
        kit.servo[ch].actuation_range = SERVO_RANGE_DEG

    center = SERVO_RANGE_DEG / 2  # 135°

    if args.leg:
        joints = LEG_CHANNELS[args.leg]
        print(f"归中 {args.leg.upper()} 腿:")
    else:
        joints = list(CHANNEL_MAP.keys())
        print("归中全部 12 个舵机:")

    for name in joints:
        ch = CHANNEL_MAP[name]
        print(f"  CH{ch:2d} ({name:15s}) -> {center:.0f}°", end=" ", flush=True)
        kit.servo[ch].angle = center
        time.sleep(0.3)
        print("OK")

    print()
    print("=" * 50)
    print("  全部归中完成！")
    print()
    print("  下一步操作：")
    print("  1. 确认所有舵机已停在中位")
    print("  2. 安装舵机角(horn)，使腿部指向正下方")
    print("  3. 用 M2 自攻螺丝锁紧舵机角")
    print("  4. 组装连杆和脚掌")
    print("=" * 50)

    input("\n按 Enter 释放舵机(松弛)...")
    for ch in range(16):
        kit.servo[ch].angle = None
    print("舵机已释放")


if __name__ == "__main__":
    main()

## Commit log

2026-04-07 feat: 四足机器恐龙 PyBullet 仿真项目初始化
    - URDF 模型：基于 SpotMicro 尺寸的 12-DOF 恐龙四足（4腿×3关节）
    - 仿真核心：PyBullet headless 仿真，支持 IK、站立、小跑步态
    - 测试工具：benchmark（稳定性/速度/扰动恢复）、yaw 诊断、速度扫描、扰动扫描
    - 可视化：渲染截图脚本、视频录制脚本、本地 HTTP 预览服务
    - 仿真日志：站立/小跑/爬行仿真数据 + benchmark 通过结果
    [dino_quadruped.urdf]
2026-04-07 docs: 添加完整硬件电路与结构设计文档
    - hardware_architecture.md: 系统框图、电源架构、I2C总线、控制环路
    - wiring_diagram.md: 完整接线图（电源/I2C/PCA9685/MPU6050/舵机）
    - mechanical_design.md: 机械结构、腿部装配、重心分析、组装顺序
    - bom.csv: 完整BOM采购清单（含淘宝关键词、优先级、价格）
    [bom.csv]
2026-04-07 feat(rl): 添加 PPO 强化学习训练环境
    - dino_env.py: Gymnasium 环境 wrapper
    - Observation: 36维 (body姿态+速度+关节角度/速度+相位时钟)
    - Action: 12维连续关节角度 (normalized [-1,1])
    - Reward: 前进速度 - 能耗 - 姿态偏差 - 侧滑 + 存活奖励
    - Termination: 高度<5cm 或 roll/pitch>70°
    - train_ppo.py: PPO训练脚本
    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
2026-04-07 feat(rl): 添加 RL 训练环境与 PPO 训练脚本
    - dino_env.py: Gymnasium 环境，36维观测、12维动作、多目标奖励函数
    - train_ppo.py: PPO训练（SB3），支持8并行环境、TensorBoard、断点续训
    - .gitignore: 排除训练产物（模型权重/日志/checkpoint）
    - 训练已启动: 2M步，RTX 2080 Ti
2026-04-07 feat(rl): 添加 foot contacts 观测、评估修复与可视化脚本
    - dino_env: 观测空间从 36 维扩展到 40 维，新增 4 个足部接触传感器
    - train_ppo: 评估优先使用 best_model（避免并行训练覆盖问题）
    - 新增 scripts/record_rl_video.py 录制 RL 策略视频
    - 新增 scripts/gen_comparison_chart.py 生成训练曲线对比图表
2026-04-07 feat: 添加硬件设计文档、评估视频录制脚本与训练评估结果
    新增接线图、机械结构设计、硬件架构三份硬件文档；
    添加 RL 策略评估视频录制与训练曲线生成脚本；
    包含 baseline vs RL (500K) 对比评估摘要。
2026-04-08 feat(rl): v6 训练完成 — 首次实现稳定前向行走
    v6 核心改进：速度奖励翻倍(1.5→3.0)、存活奖励降低(3.0→2.0)、
    惩罚项减半、3层网络(256→128→64)、PPO调参(n_steps=4096)。
    最终评估：100%存活率、前进速度0.23m/s（50x baseline）、
    行走距离4.45m（222x baseline）。已知问题：腿部抖动待v7优化。
2026-04-08 feat(rl): v7 anti-tremor 参数调整 + 添加 README
    v7 针对 v6 腿部抖动问题的优化：
    - 控制频率 60Hz→120Hz (action_repeat 4→2, max_steps 1000→2000)
    - 动作平滑性惩罚加强 -0.015→-0.04
    - 新增关节加速度惩罚 -0.002×Σ(Δjoint_vel²)
    - 足底接触奖励增大 0.15→0.25/foot
    - 步态相位奖励增大 0.5→0.7
    - 默认训练步数 500K→5M, 并行环境 4→8
    - 添加项目 README.md
2026-04-08 feat(rl): v7 训练完成 — 5M步 anti-tremor 策略
    v7 完整训练结果(5M步, 3.15h):
    - 总奖励 12,321 (v6的2.3倍)
    - 前进速度 0.229 m/s (与v6持平)
    - 100%存活率 (2000/2000步)
    - Vx波动收敛, 步态质量显著提升
    更新评估脚本适配v7参数(action_repeat=2, max_steps=2000),
    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
2026-04-14 feat(rl): add Domain Randomization for sim2real transfer
    - dino_env.py: add DR_RANGES (mass, friction, damping, sensor noise,
    action delay, random pushes, torque scaling), _sample_dr() per-episode
    sampling, progressive dr_strength support
    - train_ppo.py: add DRScheduleCallback for progressive DR warmup (0→100%
    over first 30% of training), --dr and --dr-warmup CLI args
    - 5M steps DR training completed: reward 158→5187 (33x), convergence
    CV=3.2%, forward speed 3-4x hand-tuned baseline
    - Add sim2real_transfer.md docs and eval visualization script
2026-04-15 feat: 添加硬件测试脚本、升级规划文档与评估产出
    - 新增 hardware/ 硬件验证脚本（I2C扫描、舵机测试、IMU测试、站立/小跑测试）
    - 新增升级路线、硬件对比、舵机对比、CHAMP框架、硬件验证流程等规划文档
    - 新增 v7 5M步训练评估 GIF 与高质量渲染/录制脚本
2026-04-22 feat(cad+docs): 更新CAD图纸匹配实际订单 + 完善sim2real文档
    - MPU6050: 去掉M2.5螺丝孔改为2mm扎带孔(实物无安装孔)
    - 电源开关: Φ12.5mm → Φ16.5mm(实际订单为16mm金属钮子开关)
    - sim2real_transfer.md: 新增控制频率适配章节(50Hz/120Hz对比)
    - 新增硬件升级变更清单(Phase1→Phase2完整变更)
    [body_bottom.dxf, body_top.dxf]
2026-04-23 docs(cad): 添加CAD孔位说明文档 + 修复开关与铜柱重叠
    - 新增 cad/README.md: 顶板/底板全部孔位坐标、用途、安装方式说明
    - 修复电源开关位置避开铜柱S4(100,10)，移至(130,10)
    - 包含图层说明、ASCII布局图、组装顺序
    [body_bottom.dxf, body_top.dxf]
2026-04-23 feat(cad): PCA9685实测孔位(25×61mm, Φ2mm四角距边3mm)
    - 取消PCA9685安装孔注释，填入实测尺寸: 孔距19×55mm
    - PCA中心从y=28上移至y=31，避免底部孔距板边<3mm
    - 更新README孔位表和布局图
    [body_bottom.dxf, body_top.dxf]
2026-04-30 [add] 3D visualization, leg structure docs, and hardware verification scripts
    - assembly_3d_threejs.html: Refactored Three.js visualization with proper joint hierarchy (Hip → Shoulder → Knee groups)
    - Fixed rotation axes for shoulder/knee joints (z-axis for forward/backward motion)
    - Implemented trot gait with FL+RR and FR+RL synchronization (180° phase)
    - Added direction multiplier for left/right leg symmetry
    - cad/ module: Assembly visualization tools
    - assembly_3d_view.html: Interactive 3D model viewer
    - assembly_diagram.md: Visual assembly structure documentation
    - visualize_assembly.py: Script to generate assembly visualizations
    - visualize_real_components.py: Compon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
    [visualize_real_components.py]
2026-04-30 [update] Enhanced URDF with detailed servo brackets and hardware specs
    Based on procurement list (四足机器恐龙_采购清单.xlsx), added comprehensive
    mechanical details to URDF model:
    ## New Features
    - Added 8 bracket links (4× hip_bracket, 4× knee_bracket)
    - Hip brackets: 40×50×20mm aluminum U-brackets for shoulder servo mounting
    - Knee brackets: 30×40×15mm aluminum brackets at upper leg base
    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
    [dino_quadruped.urdf]
2026-04-30 [add] Visualization tools guide and URDF compatibility testing
    ## 新增文档
    - docs/可视化工具使用指南.md: 完整的URDF/DXF查看工具指南
    - 在线URDF Viewer (https://gkjohnson.github.io/urdf-loaders)
    - DXF在线查看器 (https://sharecad.org)
    - PyBullet/Three.js 本地可视化
    - LibreCAD、ROS工具使用说明
    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
2026-04-30 [add] 3D print specifications and simplified STL files for Taobao seller
    - Add 5 STL files: hip/knee brackets, upper/lower legs, horn adapter
    - Add detailed print specifications document (dimensions, holes, tolerances)
    - Add STL usage guide explaining required modifications for seller
    - Add Python script to regenerate STL files if needed
    [hip_bracket.stl, horn_adapter.stl, knee_bracket.stl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]
2026-04-30 [update] Documentation navigation and visualization enhancements
    - Enhanced README.md: Added organized document navigation with 4 categories
    - Hardware Design & Procurement: mechanical design, hardware architecture, upgrades, BOM
    - Leg Structure & 3D Printing: detailed specs, print parameters, supplier guides
    - Software & Deployment: visualization, training, frameworks, integration, verification
    - Visualization: Three.js interactive assembly diagram with servo demos
    - Enhanced assembly_3d_threejs.html: Expanded legend with comprehensive component details
    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
2026-05-08 [add] Raspberry Pi USB LAN network configuration guide
    - Comprehensive network setup documentation for USB hub connection
    - Explains why eth0 lacks IP address and how to configure it
    - Four configuration methods: temporary, permanent (/etc/network/interfaces), netplan, and startup script
    - Detailed network principles: subnet design, IP allocation, ARP resolution
    - Diagnostic steps and troubleshooting guide
    - Quick diagnostic script for connection testing
    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
2026-05-08 [update] Add WiFi configuration and network routing troubleshooting
    - WiFi connection methods: WPA Supplicant configuration
    - Network routing priority issue analysis (metric values, route precedence)
    - Root cause: eth0 and wlan0 both have default routes with conflicting priorities
    - Solutions: delete conflicting route, configure metric, or use policy routing
    - Permanent configuration via dhcpcd.conf with interface-specific metrics
    - Complete diagnostic script for network troubleshooting
    - Installation steps for adafruit-circuitpython-servokit after WiFi setup
    - Full workflow from WiFi setup to servo testing
    Explains:
    - Why dual network interfaces cause routing conflicts
    - How Linux metric v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
2026-05-08 [add] Detailed STL files with precise holes and features
    - Created generate_stl_detailed.py script for detailed STL generation
    - Generated 5 detailed STL files with all features:
    - hip_bracket_detailed.stl: 4×servo holes (Φ3.2), 2×bearing holes (Φ5)
    - knee_bracket_detailed.stl: 4×servo holes, 2×bearing holes
    - upper_leg_detailed.stl: hollow tube (Φ10 outer, Φ6 inner) with connection ears and M3 holes
    - lower_leg_detailed.stl: hollow tube (Φ8 outer, Φ5 inner) with ear and foot pad hole (Φ15)
    - horn_adapter_detailed.stl: disk with center axis hole (Φ6) and 4×M2 fixing holes
    - Updated STL usage guide with detailed specifications:
    - Comparison table: simplified vs detai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
    [hip_bracket_detailed.stl, horn_adapter_detailed.stl, knee_bracket_detailed.stl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]
2026-05-08 [fix] 修复 STL 文件生成脚本，使用布尔差集生成真实孔位
    - 使用 trimesh 库替代手动几何合并，实现正确的布尔运算
    - 修复孔位从凸起变为凹陷的问题
    - 优化孔位深度和位置，确保可视化时清晰可见
    - 添加硬件设计校准文档，记录舵机实际尺寸和设计问题
    变更:
    - generate_stl_detailed.py: 重写使用 trimesh.difference() 进行布尔差集
    - 所有 *_detailed.stl: 重新生成，孔位现在是真实的凹陷
    - hardware_design_calib.md: 新增校准文档，包含舵机尺寸、DXF 孔位分析
    [hip_bracket_detailed.stl, horn_adapter_detailed.stl, knee_bracket_detailed.stl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]
2026-05-08 [add] 添加电池尺寸问题分析和修复方案
    发现问题:
    - 实际电池: 格氏 5000mAh 2S, 132×40×17mm
    - body_top.dxf 电池槽: 仅 55×30mm
    - 差距: 长度差77mm, 宽度差10mm, 电池完全无法放入
    修复方案:
    - 方案1 (推荐): 扩大电池槽至 135×42mm
    - 方案2: 更换为更小电池 (不推荐, 续航减半)
    - 方案3: 电池外挂 (临时方案)
    - hardware_design_calib.md: 新增 body_top.dxf 电池问题分析
    - assembly_3d_threejs.html: 更新电池规格，添加设计问题警告
    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
2026-05-08 [fix] 修复 DXF 文件尺寸问题，更新 3D 可视化
    DXF 修复:
    1. body_top_fixed.dxf
    - 电池槽: 55×30mm → 135×42mm (增加77mm长度, 10mm宽度)
    - 原文件已备份为 body_top_backup.dxf
    2. body_bottom_fixed.dxf
    - 舵机孔距: 20mm → 10mm (符合 DS3218 标准)
    - 修复 8 对舵机安装孔 (前腿4对 + 后腿4对)
    - 原文件已备份为 body_bottom_backup.dxf
    3D 可视化更新:
    - 电池模型: 70×30×50mm → 132×40×17mm (真实尺寸)
    - 图例: 更新电池规格, 标记已修正
    - 状态: 设计问题警告 → 设计修正完成
    验证:
    - ✓ 所有舵机孔间距均为精确 10mm
    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
    [body_bottom_fixed.dxf, body_top_fixed.dxf]
2026-05-08 [refactor] 文件清理：统一使用修复版本，删除临时文件
    重命名和清理:
    - *_detailed.stl → *.stl (删除 detailed 后缀)
    - body_*_fixed.dxf → body_*.dxf (使用修复版本)
    - 删除测试文件和备份文件
    现在所有文件都是修复后的最终版本:
    - ✓ STL 文件包含真实孔位（布尔差集）
    - ✓ DXF 文件包含正确尺寸（电池槽135×42mm, 舵机孔10mm）
    - ✓ 文件命名简洁清晰
    [body_bottom.dxf, body_bottom_fixed.dxf, body_top.dxf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]
2026-05-08 [docs] 添加舵机U型槽固定方式详细说明
    新增文档:
    - cad/servo_mounting_guide.md: U型槽原理、尺寸计算、组装步骤
    - 包含ASCII示意图、常见问题、设计建议
    - 针对DS3218舵机的完整固定方案
